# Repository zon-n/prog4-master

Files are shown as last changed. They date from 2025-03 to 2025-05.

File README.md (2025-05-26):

# Projet d'intégration SIM H25

#### Note: Voir le répo [slave](https://github.com/zon-n/prog4-slave) pour les informations sur l'appareil slave du projet

## Table des matières

1. [Présentation](#présentation)  
2. [Objectifs du projet](#objectifs-du-projet)  
3. [Matériel utilisé](#matériel-utilisé)  
4. [Architecture technique](#architecture-technique)  
5. [Schémas et diagrammes de classes](#schémas-et-diagrammes-de-classes)
6. [Installation et assemblage](#installation-et-assemblage)
7. [Description de l’algorithme de contrôle de traction](#description-de-lalgorithme-de-contrôle-de-traction)  
8. [Tests et résultats](#tests-et-résultats)  
9. [Améliorations supplémentaires](#améliorations-supplémentaires)
10. [Ressources supplémentaires](#ressources-supplémentaires)  

---

## Présentation

### Algorithme de contrôle de traction pour optimiser la performance et le pilotage d'un véhicule imprimé en 3D

Ce projet vise à concevoir une voiture téléguidée optimisée à l'aide d'un algorithme de contrôle de traction. Le véhicule, inspiré du design de la Formule 1, utilise un châssis imprimé en 3D et est équipé d'un accéléromètre, d'un gyroscope et d'un magnétomètre. L'architecture du projet est modulable et open-source, permettant une évolution facile et une personnalisation par la communauté. Ce projet a pour but d'améliorer l'adhérence en virage et d'optimiser la performance globale du véhicule à travers un contrôle précis du moteur en fonction des conditions de conduite.

---

## Objectifs du projet

Les objectifs principaux du projet sont les suivants :

- Concevoir un châssis rigide et léger via un logiciel de CAO, adapté à un modèle de véhicule téléguidé.
- Imprimer en 3D et assembler un véhicule fonctionnel, prêt à être testé sur différentes surfaces et en virage.
- Intégrer des capteurs de mouvement (accéléromètre, gyroscope, magnétomètre) pour analyser la dynamique du véhicule en temps réel.
- Développer un algorithme de contrôle PID pour améliorer l'adhérence en virage et optimiser les performances du véhicule sur différents types de surface (asphalte, gravier, etc.).

---

## Matériel utilisé

La liste complète du matériel utilisé est disponible dans le fichier `BOM.xlsx`. Voici un aperçu du matériel principal :

- **Châssis** : Imprimé en 3D
- **Capteurs** : MPU9250 (accéléromètre, gyroscope, magnétomètre)
- **Moteur** : Moteur à courant continu contrôlé par PWM
- **Microcontrôleur** : ESP32 (pour le contrôle des moteurs et la communication Wi-Fi)
- **Batterie** : Li-Po 7.4V pour alimenter les moteurs et la carte électronique
- **Module Wi-Fi** : ESP32 intégré pour la communication sans fil
- **Structure et composants supplémentaires** : Roues, suspensions, pièces imprimées en 3D, etc.

---

## Installation et assemblage

### Modélisation des composantes mécaniques

Les fichiers `.step` contenant les modèles 3D des composantes mécaniques sont situés dans le dossier `/CAD`. Ils peuvent être imprimés en 3D avec une imprimante avec une surface d'impression de au moins 250 x 250 x 250 mm.

Les modèles peuvent êtres importés dans un logiciel de Slicer comme [PrusaSlicer](https://www.prusa3d.com/page/prusaslicer_424/) ou [OrcaSlicer](https://github.com/SoftFever/OrcaSlicer).

Il est recommandé d'imprimer les modèles avec les paramètres suivants:

```* Tête 0.4mm ou 0.6mm
* 40% Remplissage
* Remplissage de type Gyroid ou Cubic
* Au moins 3 murs de remplissage
* Matériaux recommandés: ABS, ASA
```

### Installation des logiciels et librairies

Le projet est développé à l'aide du framework **PlatformIO** pour le développement embarqué et des librairies Arduino.

1. **Installation de PlatformIO** : [https://platformio.org/install](https://platformio.org/install)

2. **Installation de l'Arduino IDE** : [https://www.arduino.cc/en/software](https://www.arduino.cc/en/software)

3. **Librairies nécessaires** :

* `MPU9250` : pour lire les données de l'accéléromètre, du gyroscope et du magnétomètre
* `PID` : pour appliquer l'algorithme de régulation PID sur le moteur
* `ESPAsyncWebServer` : pour créer une interface Web asynchrone sur l'ESP32
* `AsyncTCP` : utilisé avec `ESPAsyncWebServer` pour la communication réseau
* `Arduino_JSON` : pour manipuler les données JSON dans les échanges Web
* `WiFi` : pour connecter l'ESP32 au réseau sans fil
* `HighCharts` : Libraire Javascript pour la génération de diagrammes. 
   #### Voir les [ressources supplémentaires](#ressources-supplémentaires) pour plus d'informations

### Accès à la page Web de télémétrie
Avant de téléverser le programme `c++` sur le ESP32, il faudra charger les données `html`, `css` et `javascript` sur le système de mémoire interne `LittleFS` du ESP32. Le API de PlatformIO permet d'écrire les fichiers du front end avec la fonction `Upload Filesystem Image` dans l'onglet de l'extension PlatformIO. 

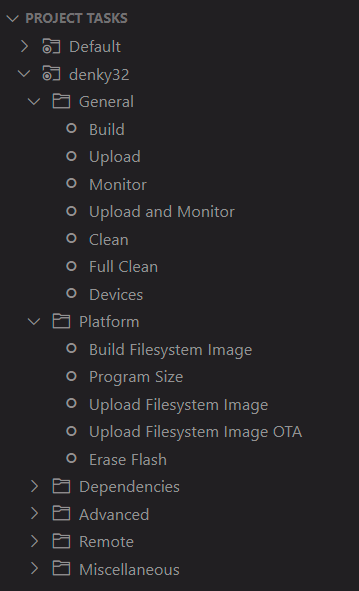
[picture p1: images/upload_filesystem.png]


Il faudra aussi modifier les informations du réseau local désiré dans le fichier `/src/main.cpp`. Les variables `*ssid` et `*password` seront à modifier

Exemple:

```c
const char *ssid = "SSID";
const char *password = "PASSWORD";
```

Changé à 

```c
const char *ssid = "MY_SSID";
const char *password = "MY_PASSWORD";
```

Lorsque le programme sera initialisé, la méthode `setup()` initialisera une instance d'un serveur asynchrome (AsyncWEbServer). L'addresse local du serveur sera imprimée sur la console. Il faudra naviguer à cette addresse sur le réseau local pour y avoir accès. 

---

## Architecture technique

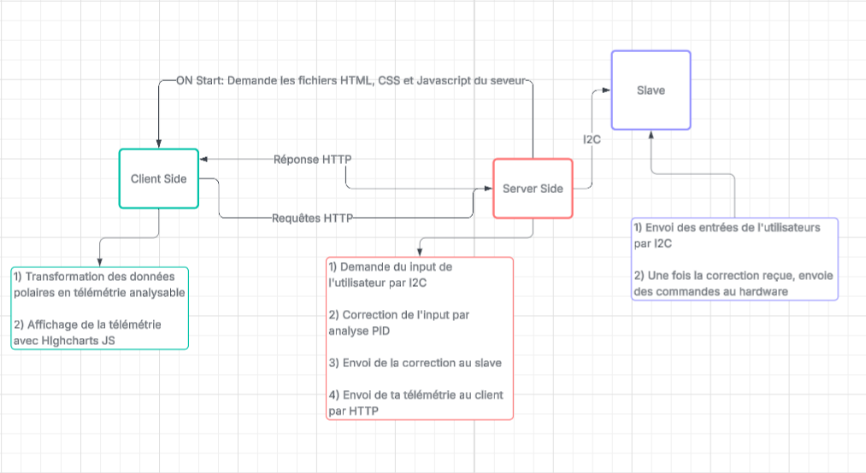
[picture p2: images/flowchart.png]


### Modules principaux

1. **Acquisition des données**  
   - **Capteur MPU9250** : Lecture des valeurs d'accélération, de vitesse angulaire et de champ magnétique pour déterminer la position, la vitesse et l'orientation du véhicule. La combinaison des senseurs pour améliorer la qualité des données est éffectuée par la librairie [MPU9250](https://github.com/hideakitai/MPU9250)

2. **Traitement des données**  
   - **Filtrage et analyse** : Comparaison des données captées par les capteurs avec les objectifs de conduite de l'utilisateur (vitesse, angle de virage, etc.).
   - **Correction de l'entrée de l'utilisateur** : Utilisation des données pour ajuster les actions du système de contrôle PID.

3. **Contrôle PID du moteur**  
   - Réglage dynamique de la puissance moteur en fonction des entrées du système PID.

4. **Communication**  
   - **Transmission Wi-Fi** : Envoi des données de télémétrie à une page Web en temps réel pour visualiser les performances du véhicule.
   - **Envoi de la correction par I2C** : Communication bidirectionnelle pour envoyer des corrections à l'algorithme de contrôle du moteur en fonction des ajustements faits par l'utilisateur ou le système.
   - **Requête http**: Envoi des requêtes pour ajuster les paramètres de l'algorithme PID en temps réel.

5. **Interface utilisateur (UI)**  
   - **Graphique de télémétrie**: Affichage graphique de la puissance des moteurs en temps réel
   - **Réglage PID à distance** : Interface Web permettant de modifier les paramètres du PID en temps réel.
   - **Courbe d'analyse** : Affichage graphique des entrées et sorties du système PID pour analyser la performance du véhicule.

---

## Schémas et diagrammes

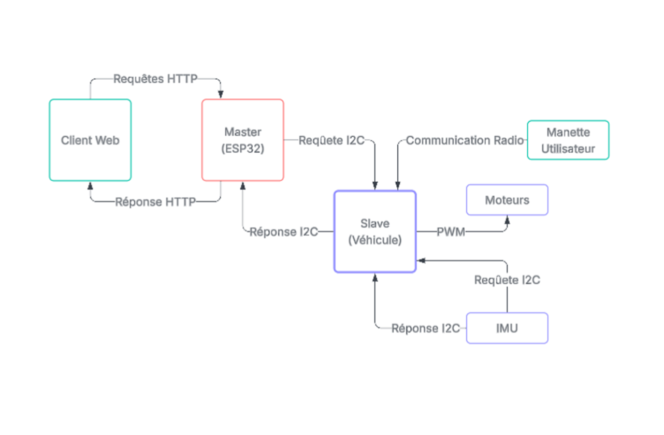
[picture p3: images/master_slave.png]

---

### Protocoles de communication

Le projet utilise plusieurs protocoles pour gérer les différents composants :

1. **PWM** : Utilisé pour contrôler la vitesse des moteurs en ajustant la largeur des impulsions électriques.
2. **I2C** : Utilisé pour la communication avec le capteur MPU9250. Établit la connection d'envoi binaire avec un appareil [slave](https://github.com/zon-n/prog4-slave)
3. **Wi-Fi** : Pour la communication sans fil entre le véhicule et la page Web pour afficher la télémétrie et ajuster les paramètres du système.
4. **HTTP** : Pour la requête de données et la calibration en temps réel à travers l'interface web. 
5. **Radio 2.4Ghz** : Communication des commandes d'utilisateurs à longue portée.

---

## Description de l’algorithme de contrôle de traction

L'algorithme de contrôle de traction utilise un **PID** (Proportionnel-Intégral-Dérivé) pour réguler la vitesse des moteurs du véhicule et optimiser son adhérence pendant les virages. Voici un aperçu de son fonctionnement :

1. **Proportionnel** : La réponse est directement proportionnelle à l'écart entre la vitesse mesurée et la vitesse souhaitée.
2. **Intégral** : Permet de compenser les erreurs accumulées sur le temps pour corriger les déviations lentes.
3. **Dérivé** : Réagit aux changements rapides de l'écart, ajustant la puissance du moteur pour éviter les oscillations.

L'algorithme ajuste dynamiquement la puissance des moteurs en fonction de l'adhérence de la surface, de la vitesse et de l'angle de virage.

---

## Tests et résultats

### Tests effectués

- **Tests de vitesse** : Validation de la capacité du véhicule à atteindre et maintenir une vitesse constante.
- **Tests en virage** : Vérification de la performance du contrôle PID en fonction de différents angles de virage et types de surface.
- **Tests de contrôle par interface Web** : Vérification de la performance de la platforme Web hébergé sur le ESP32. L'accès local permet une connection facile à la page web

### Résultats obtenus

- Le télémétrie montre une déviation entre l'entrée d'utilisateur et la correction
- Le véhicule roule droit lors des test élémentaires
- La télémétrie en temps réel a permis de visualiser l'impact des réglages PID sur la performance du véhicule

#### Exemple de résultat

Avant l'activation de la contrôle de traction, l'appareil Master demande le signal de contrôle reçu par l'appareil Slave par **I2C**. Il renvoie ensuite les données sur la page web et ne corrige pas la donnée. L'entrée de l'utilisateur est donc la même que la sortie sur les moteurs.

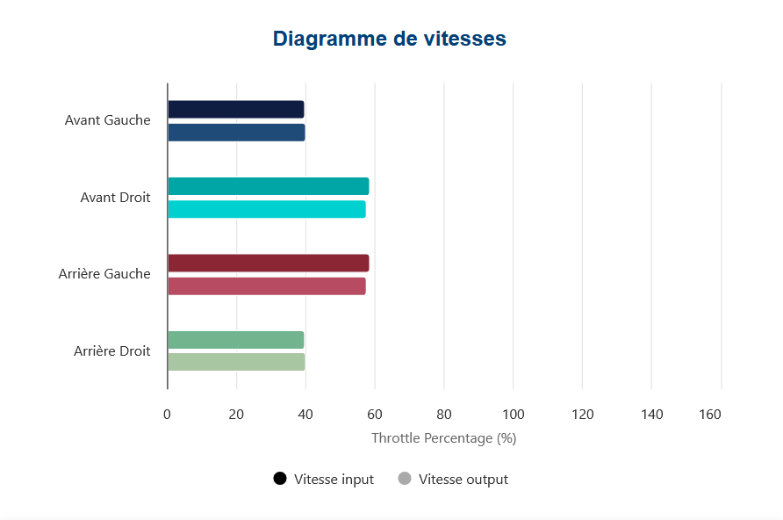
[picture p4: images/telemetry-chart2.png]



Après l'activation de la contrôle de traction, on voit une déviation entre les entrés d'utilisateurs et la sortie sur les roues. Le signal de contrôle demandé par l'appareil Master du Slave par **I2C** est traité par l'algoritheme de **PID** pour être ensuite renvoyé par **I2C** au slave pour actionner les moteurs. Les données sont ensuites envoyées sur la page web pour analyse.

### Améliorations supplémentaires
- Calibration des consantes PID: Jusqu'à maintenant la calibration des constantes proportionnelles, intégrales et dérivées ont été faites à la main. Dans certains cas, la performance était inférieure après le contrôle PID que sans. Il serait donc envisageable de développer un algorithme de calibration automatique pour trouver les constantes PID optimales pour des conditions variées. 
- Incorporation de plus d'information télémétriques pour analyse sur le front-end Javascript du client
- Optimisation du système mécanique pour réduire les bruits des signaux des capteurs

---

## Ressources supplémentaires

- **Documentation sur l'ESP32** : [https://docs.espressif.com/](https://docs.espressif.com/)
- **Documentation sur PlatformIO**: [https://platformio.org/](https://platformio.org/)
- **Docoumentation sur Arduino**: [https://www.arduino.cc/en/software/](https://www.arduino.cc/en/software/)

- **Hyperliens vers les répositoires Github des libraires utilisées**
   * [hideakitai/MPU9250@](https://github.com/hideakitai/MPU9250)
   * [br3ttb/PID@](https://github.com/br3ttb/Arduino-PID-Library)
   * [esp32async/AsyncTCP](https://github.com/ESP32Async/AsyncTCP)
   * [esp32async/ESPAsyncWebServer](https://github.com/ESP32Async/ESPAsyncWebServer)
   * [arduino/ArduinoJSON](https://github.com/arduino-libraries/Arduino_JSON)
   * [HighChartsJS](https://www.highcharts.com/)

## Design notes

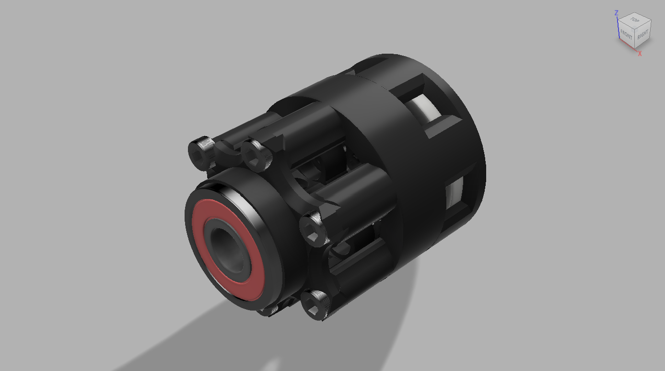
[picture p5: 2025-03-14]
images/gearbox_mk3.png

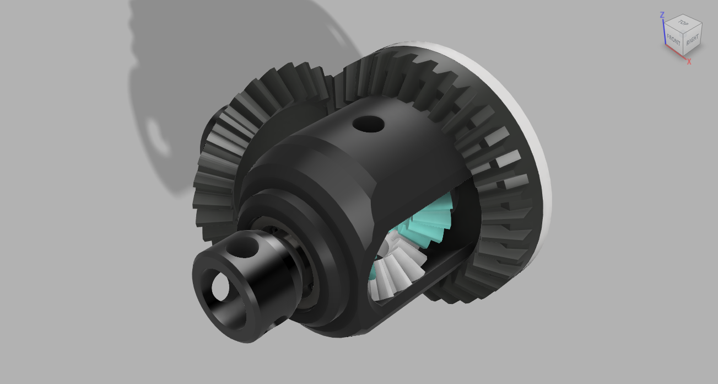
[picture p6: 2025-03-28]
images/differentiel_mk1.png

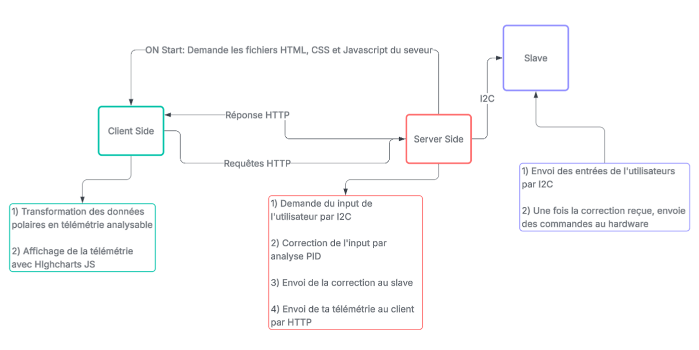
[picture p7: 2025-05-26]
image.png

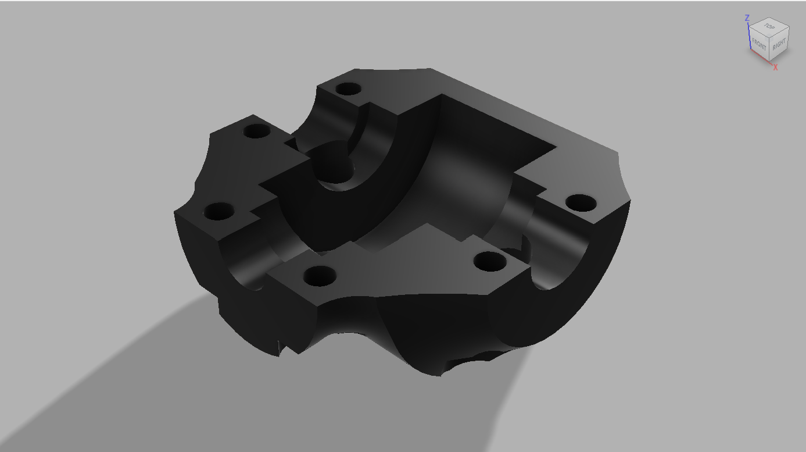
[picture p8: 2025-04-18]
images/differential_holder_mk1_inside.png

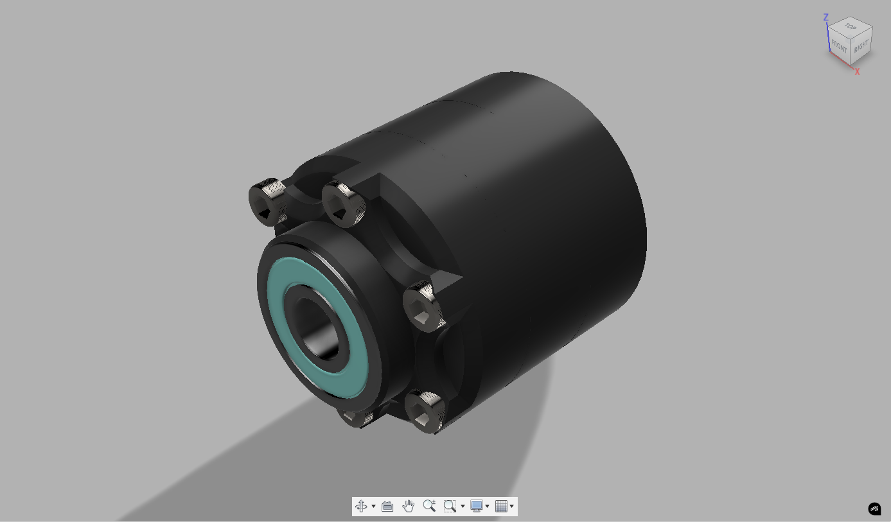
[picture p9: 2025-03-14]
images/gearbox_mk1.png

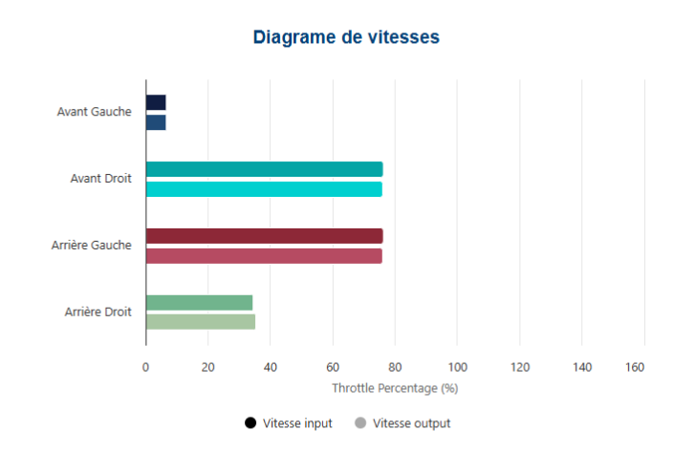
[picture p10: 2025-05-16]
images/telemetry-chart.png

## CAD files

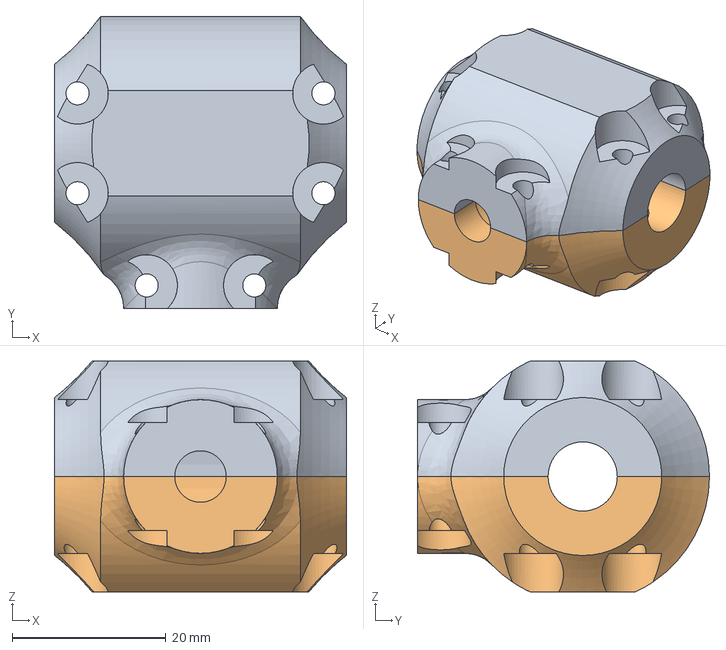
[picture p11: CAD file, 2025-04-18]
CAD/modèles/Differential Holder Mk1.step
38.0 x 38.0 x 30.0 mm
Lower case
Upper case

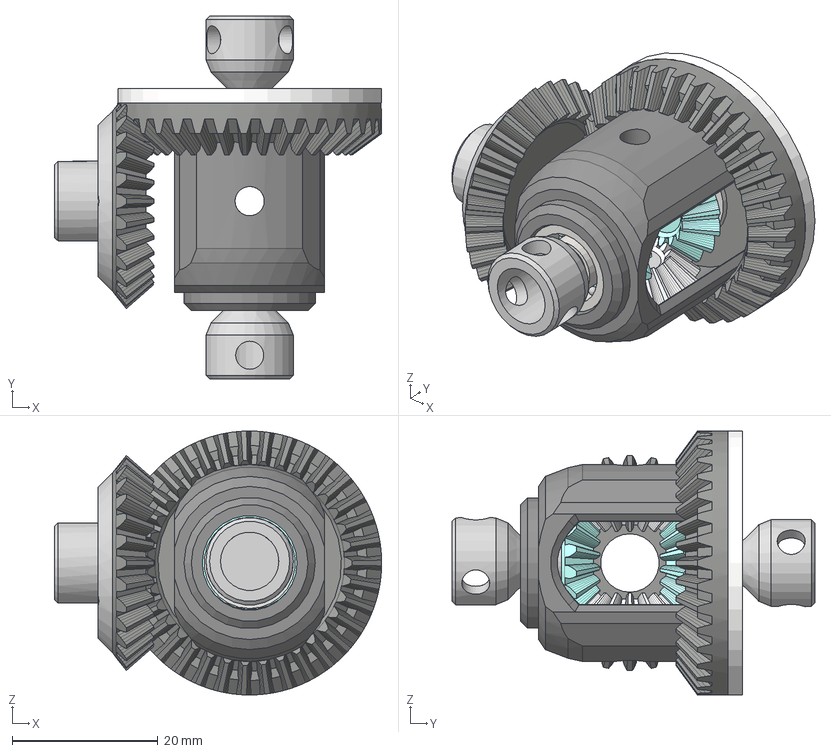
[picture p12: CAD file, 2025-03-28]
CAD/modèles/Differentiel Mk1.step
44.9 x 49.8 x 36.2 mm
Side Gear x 2
Spider Gear x 2
Wheel Shaft Connect L
Wheel Shaft Connect R
Shaft Connect
Carier Plate
Ring Gear

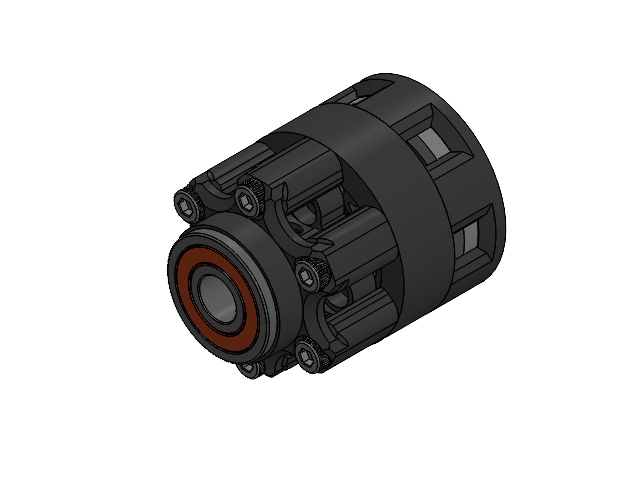
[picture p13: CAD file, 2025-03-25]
CAD/Solidworks/Transmission/Planetary Gearbox.SLDASM
Spur gear (11 teeth).step x 3
Base Connector.step
Carrier Front.step
Inner Ring001.step
Ring Gear.step
M3x16 v1 v1.step x 6
Seal 002.step
Bearing Host.step
Cage clone 002.step
Gearbox Cover.step
Cage 001.step
Outer Ring001.step
Carrier Back.step
Seal 001.step

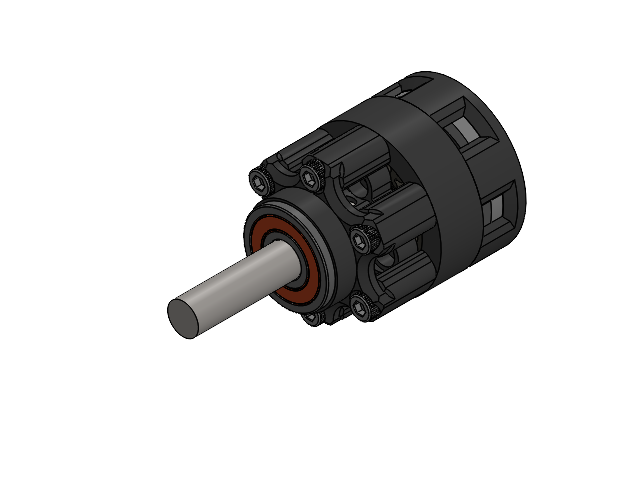
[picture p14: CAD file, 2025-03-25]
CAD/Solidworks/Transmission/Transmission.SLDASM
Spur gear (11 teeth).step x 3
Base Connector.step
Carrier Front.step
Inner Ring001.step
Ring Gear.step
M3x16 v1 v1.step x 6
Seal 002.step
Bearing Host.step
Cage clone 002.step
Gearbox Cover.step
Cage 001.step
Outer Ring001.step
Carrier Back.step
Seal 001.step
8x45mm Shaft

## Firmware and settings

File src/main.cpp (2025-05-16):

#include <Arduino.h>
#include <Wire.h>
#include <MPU9250.h>
#include <WiFi.h>
#include <AsyncTCP.h>
#include <ESPAsyncWebServer.h>
#include "LittleFS.h"
#include <Arduino_JSON.h>
#include "drive/traction_control.h"
#include <utils/vecteur.h>

#define CRC_I2C_ADDRESS 0x02 
#define MPU_I2C_ADDRESS 0x68
#define UPDATE_DELAY 100

// Replace with your network credentials
const char *ssid = "SSID";
const char *password = "PASSWORD";

// Création d'un serveur web asynchrone sur le port 80
AsyncWebServer server(80);
AsyncEventSource events("/events"); // Création d'une source d'événements asynchrone pour le serveur
JSONVar readings; // Objet JSON pour stocker les lectures des capteurs

unsigned long lastTime = 0;
unsigned long timerDelay = 100;

// Instances nécessaires pour le système de contrôle de traction	
MPU9250 mpu;
TractionControl tractionControl;
Vecteur2 driverInput;
Vecteur2 correctedDriverInput = driverInput;

int8_t speed;
int8_t orientation;

/**
 * @brief Fonction pour obtenir les lectures des capteurs
 * @return Renvoie une chaîne JSON contenant les lectures des capteurs
 */
String getSensorReadings()
{
    readings["input_speed"] = driverInput.x;
    readings["input_orientation"] = driverInput.y;
    readings["output_speed"] = correctedDriverInput.x;
    readings["output_orientation"] = correctedDriverInput.y;
    readings["kp"] = tractionControl.kp_steering;
    readings["ki"] = tractionControl.ki_steering;
    readings["kd"] = tractionControl.kd_steering;

    String jsonString = JSON.stringify(readings);
    return jsonString;
}

/**
 * @brief Initialiser le système de fichiers LittleFS utilisé par ESP32 pour stocker des fichiers du serveur web
 */
void initLittleFS()
{
    if (!LittleFS.begin())
    {
        Serial.println("An error has occurred while mounting LittleFS");
    }
    else
    {
        Serial.println("LittleFS mounted successfully");
    }
}

/**
 * @brief Initialiser la connexion WiFi
 */
void initWiFi()
{
    WiFi.mode(WIFI_STA);
    WiFi.begin(ssid, password);
    Serial.print("Connecting to WiFi ..");

    // Attendre la connexion au WiFi
    while (WiFi.status() != WL_CONNECTED)
    {
        Serial.print('.');
        delay(1000);
    }
    Serial.println(WiFi.localIP());
}

/**
 * @brief Initialiser le serveur web
 */
void serverInit()
{
    initWiFi();
    initLittleFS();

    // Envoie la page HTML index.html lorsque la racine est demandée
    server.on("/", HTTP_GET, [](AsyncWebServerRequest *request)
              { request->send(LittleFS, "/index.html", "text/html"); });

    server.serveStatic("/", LittleFS, "/");

    // Renvoie un changement de valeur pour les paramètres PID lorsque la page est demandée
    server.on("/changeKP", HTTP_GET, [](AsyncWebServerRequest *request)
              {
                  double testParam = request->getParam("value")->value().toDouble();
                  request->send(LittleFS, "/index.html", "text/html");
                  tractionControl.kp_steering += testParam;
                  Serial.println("KP changed to: " + String(tractionControl.kp_steering));
                  });
    server.on("/changeKI", HTTP_GET, [](AsyncWebServerRequest *request)
              {
                  double testParam = request->getParam("value")->value().toDouble();
                  request->send(LittleFS, "/index.html", "text/html");
                  tractionControl.ki_steering += testParam;
                  Serial.println("KI changed to: " + String(tractionControl.ki_steering));
                  });
    server.on("/changeKD", HTTP_GET, [](AsyncWebServerRequest *request)
              {
                  double testParam = request->getParam("value")->value().toDouble();
                  request->send(LittleFS, "/index.html", "text/html");
                  tractionControl.kd_steering += testParam;
                  Serial.println("KD changed to: " + String(tractionControl.kd_steering));
                  });


    // Renvoie les lectures des capteurs au format JSON par requête http
    server.on("/readings", HTTP_GET, [](AsyncWebServerRequest *request)
              {
    String json = getSensorReadings();
    request->send(200, "application/json", json);
    json = String(); });

    // Envoie sur la console lorsque le client se reconnecte
    events.onConnect([](AsyncEventSourceClient *client)
                     {
    if(client->lastId()){
      Serial.printf("Client reconnected! Last message ID that it got is: %u\n", client->lastId());
    }

    // Envoie sur la console que le client s'est connecté
    client->send("hello!", NULL, millis(), 10000); });
    server.addHandler(&events);

    server.begin();
}

/**
 * @brief Met à jour le serveur en envoyant les lectures des capteurs
 * @note Envoie un message "ping" toutes les 100ms
 * @note Envoie les lectures des capteurs au format JSON
 */
void serverUpdate()
{
    if ((millis() - lastTime) > timerDelay)
    {
        events.send("ping", NULL, millis());
        events.send(getSensorReadings().c_str(), "new_readings", millis());
        lastTime = millis();
    }
}
/**
 * @brief Fonction pour obtenir les entrées du conducteur via I2C du slave
 * @return Renvoie un vecteur contenant la vitesse et l'orientation
 */
Vecteur2 getInput()
{
    int8_t speed;
    int8_t orientation;

    // Demande de lecture de 2 octets à l'adresse I2C du slave
    Wire.requestFrom(CRC_I2C_ADDRESS, 2);
    while (Wire.available() >= 2)
    {
        speed = Wire.read();
        Wire.available();
        orientation = Wire.read();
    }

    return {speed, orientation};
}

/**
 * @brief Fonction pour envoyer les entrées corrigées au slave via I2C
 * @param correctedDriverInput Vecteur2 contenant la vitesse et l'orientation corrigées
 */
void sendCorrectedInput(Vecteur2 correctedDriverInput)
{
    // Cast la vitesse et l'orientation corrigées en int8_t car le traitement PID est fait en double
    int8_t speed = static_cast<int8_t>(correctedDriverInput.x); 
    int8_t orientation = static_cast<int8_t>(correctedDriverInput.y);

    // Envoie de la vitesse et de l'orientation corrigées au slave via I2C
    Wire.beginTransmission(CRC_I2C_ADDRESS);
    Wire.write(speed);
    Wire.write(orientation);
    Wire.endTransmission();
}

/**
 * @brief Fonction de configuration initiale, éxécutée une fois au démarrage
 * @details Initialise la connexion série, le bus I2C et le serveur web
 */
void setup()
{
    Serial.begin(115200);
    Wire.begin();
    serverInit();

    // Initialisation de la communication I2C avec le MPU9250 et calibration du module
    if (!mpu.setup(MPU_I2C_ADDRESS))
    {
         Serial.println("MPU connection failed");
         while (1)
         {
             delay(1000);
         }
     }
     else
     {
         Serial.println("MPU connection successful. Start calibration");
         mpu.calibrateAccelGyro();
         mpu.calibrateMag();
         Serial.println("Calibration successful");
     }
    tractionControl.enable(false);
}

/**
 * @brief Boucle principale, éxécutée en continu
 * @details Lit les entrées du conducteur, met à jour le MPU9250, met à jour le contrôle de traction et envoie les entrées corrigées au slave
 * @note Envoie les lectures des capteurs au format JSON
 */
void loop()
{
    driverInput = getInput();

    Serial.print("MPU status:");
    Serial.println(mpu.isConnected() ? "connected" : "disconnected");

    // Mise à jour du MPU9250
    if (mpu.update())
    {
        Serial.println("MPU update successful");
        static uint32_t prev_ms = millis();
        if (millis() > prev_ms + UPDATE_DELAY)
        {
            prev_ms = millis();
        }
    }
    else
    {
        Serial.println("MPU update failed");
    }

    Serial.print("Orientation: ");
    Serial.println(mpu.getYaw());

    // Mettre à jour le contrôle de traction avec les entrées du conducteur et l'angle de tangage
    tractionControl.update(driverInput, mpu.getYaw());

    // Corrige les entrées du conducteur avec le PID une fois le contrôle de traction mis à jour
    correctedDriverInput = tractionControl.steeringControl();
    sendCorrectedInput(correctedDriverInput);

    // Debug sur la console
    Serial.print("Driver input: ");
    Serial.print(driverInput.x);
    Serial.print(" ");
    Serial.print(driverInput.y);
    Serial.print(" Corrected driver input: ");
    Serial.print(correctedDriverInput.x);
    Serial.print(" ");
    Serial.print(correctedDriverInput.y);

    // Vérifie la connexion WiFi et redémarre si la connexion échoue
    if (WiFi.status() != WL_CONNECTED)
    {
        Serial.println("WiFi connection failed");
        initWiFi();
    }

    if (millis() - lastTime > timerDelay)
    {
        serverUpdate();
    }
}

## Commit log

2025-01-31 Communication RC à Arduino
2025-03-14 Create Planetary Gearbox
2025-03-14 Lecture du IMU
2025-03-14 Gearbox Mk1 documenté
2025-03-14 Modèle Gearbox Mk1
2025-03-14 Gearbox Mk2 documenté
2025-03-14 Gearbox Mk3 documenté
2025-03-21 Définition des fonctions de l'algorithme de contrôle de traction
2025-03-21 Implémentation des fonctions du contrôle de traction
2025-03-21 Implémentation des fonctions de conduite
2025-03-21 Initlialisation de la classe IMU
2025-03-21 Implémentation de la lecture de l'IMU
2025-03-21 Contrôle de rotation
2025-03-23 Détection d'angles par fusion de senseurs
2025-03-23 Traction control : adjustStraightLine code de base ecrit.
2025-03-23 fonction throttleControl
2025-03-25 Assemblage de la transmission sur Solidworks
    [Planetary Gearbox.SLDASM, Transmission.SLDASM]
2025-03-28 Modélisation du premier modèle de différentiel
    [Differentiel Mk1.step]
2025-03-28 Implementation des vecteurs
2025-03-28 Implementation de fonction throttleControl
2025-03-28 Migration du hardware vers ESP32
2025-03-28 Migration de platforme à ESP32
2025-03-28 Migration de platforme vers ESP32
2025-03-29 Creation des fichiers necessaires
2025-04-02 Réception et envoi de la télémétrie
2025-04-04 Ajustement du PID de contrôle de traction
2025-04-11 IMU reading
2025-04-18 Modélisation de la transmission différentielle
    [Differential Holder.step]
2025-04-20 Optimisation du modèle du différentiel
    [Differential Holder Mk1.step]
2025-05-02 Optimisation de du contrôle de traction
2025-05-02 Corrige bug converstion int pendant la lecture
2025-05-02 Fusion des algorithmes d'input, de senseurs et de traction de contrôle dans main.cpp
2025-05-12 Implémentation de la communication avec le nouveau système master-slave par I2C
2025-05-16 Documentation des fichiers de configuration de projet
